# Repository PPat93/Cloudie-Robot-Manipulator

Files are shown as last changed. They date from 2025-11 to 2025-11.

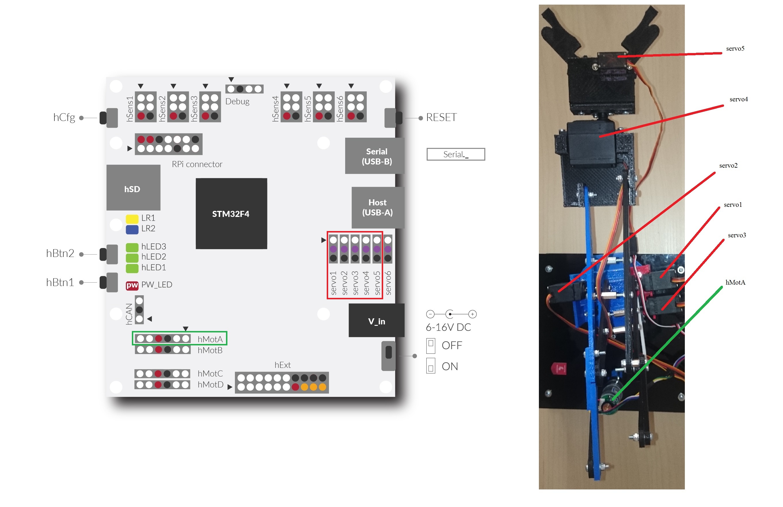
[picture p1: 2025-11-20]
electrical-wiring.jpg

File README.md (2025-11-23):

# Cloudie - 5-DOF Robotic Arm


## Overview
cloudie-duze png-1
Cloudie is a robot arm with five degrees of freedom that I created from scratch (with an overall construction inspiration from MeArm) during one of my university internships in 2016. 
Its closed-kinematic-chain architecture provides several advantages over open-chain designs - most notably higher load capacity and improved rigidity.

A key design choice was to place four of the six drives on the base, significantly reducing the mass of the moving arm. This leads to:
- higher positioning precision,
- lower inertia,
- reduced mechanical stress on the structure.

# What Cloudie Is Made Of?
Cloudie is built from a combination of 3D-printed components, servos, a DC motor with encoder, and a collection of miscellaneous parts. Its heart is the Husarion's Core2 board.

Precise List:
- 4 x TowerPro MG995 servos
- 1 TowerPro MG90S servo
- 1 DC motor with encoder
- 1 GT2 timing beltbearing
- 2 x 6000-2RS bearing
- Husarion CORE2
- 3D printed parts
- M3 screws, washers and nuts, servo screws
- several ASG BBs for the base 

## Components for printing
Below is a table with the parts that need to be printed in order to build the manipulator. Models, created in OpenSCAD format, can be found in the appropriate folder in the repository. 
mechnical-parts-list-and-numbers

# Pics











# Clips
## Separate movement:
[Separate movement](https://youtu.be/uYkaFl4qGg0)

## Rectlinear movement
[Rectlinear movement](https://youtu.be/c3nKy4OTICQ)

## Coordinates movement
[Coordinates movement](https://youtu.be/PuT0RdOZupA)

# Inversed kinematics calculations
The inverse kinematics of the manipulator was calculated manually based on the geometric relationships between its joints and connectors. These calculations allowed for the precise determination of the joint angles required to place the gripper in the desired position in space. I derived the equations based on the previously designed arm components and its complex structure. As a result, the manipulator can reach target points and follow predetermined trajectories.
The diagrams and calculations are presented below. Each diagram shows one cast of the manipulator (or part thereof).

## Calculations - Part I
part1-graphics

## Calculations - Part II 
part2-graphics

## Cleaned up calculations and results
final-cleaned-up-calcs

# Control and movement
I have created three ways to control Cloudie: separate, rectilinear, and coordinates movements. Each of them allows for a different type of motion, depending on needs. Originally, the manipulator control was designed to work via the Internet – through the HusarionCloud solution. Therefore, each original software folder contains both the code itself and a simple HTML page of the user interface used to operate the manipulator. 

## Separate movement 
The manipulator moves each drive individually - each joint separately. Works the same as in an excavator. One key = one joint.
joints-movement

## Rectlinear movement
The manipulator moves only in a straight line – along the imaginary X, Y and Z axes. One key = one axis.
rectlinear-movement-graph

## Coordinates movement  
The manipulator moves directly to predefined Cartesian coordinates. Its zero point (0,0,0) is located at the base of the manipulator - in the middle of the base bearing. The coordinates are entered up front and accepted with a single button press. 
coordinates-movement-graph

# Assembly
It’s highly recommended to assemble Cloudie from the base up to the gripper.
Starting elsewhere may cause difficulties when connecting the rotating base to the rest of the arm.
Most of the assembly process is straightforward - except for the gripper, which requires a bit more attention. The illustration below demonstrates the correct assembly method.




Once the gripper is installed, the remaining steps simply involve attaching each segment progressively from base to end-effector.

# Wiring
Thanks to the design of the CORE2 control board, all servos and motor are connected directly to the designated connectors. The connections are simple, as shown in the diagram below.
electrical-wiring

# Controller
The control board used in the manipulator's design is Husarion's Core2. It allows for the simultaneous connection of 5 servo mechanisms and 4 motors with the possibility of control via the Internet.


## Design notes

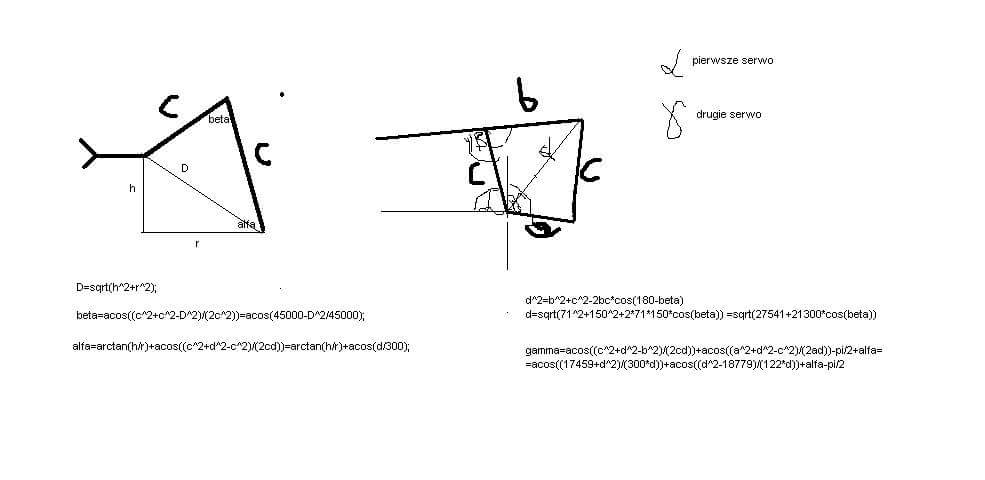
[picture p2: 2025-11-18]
orginal-kinematics-calcs/part1-original.jpg

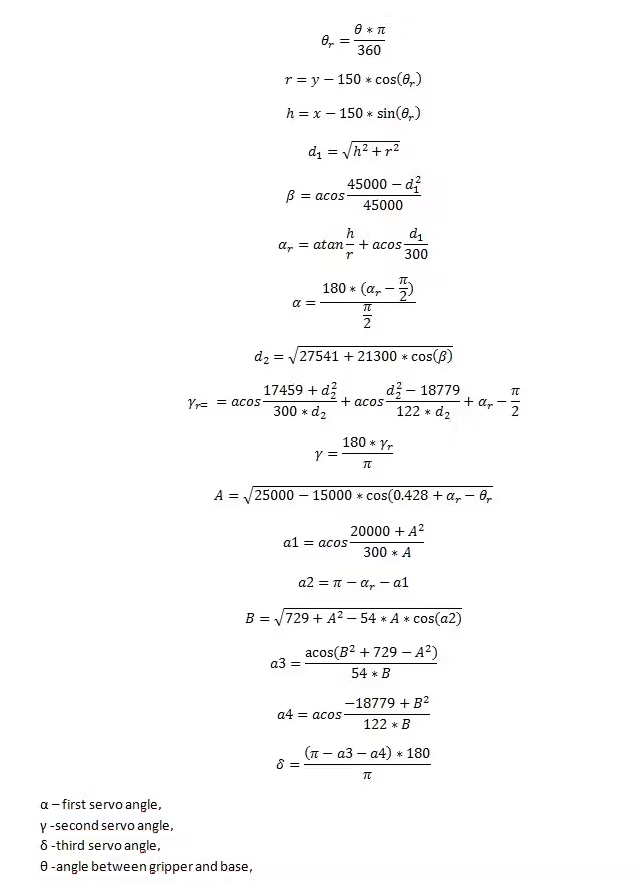
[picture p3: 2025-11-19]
revised-kinematics-calcs-and-graphics/final-cleaned-up-calcs.png

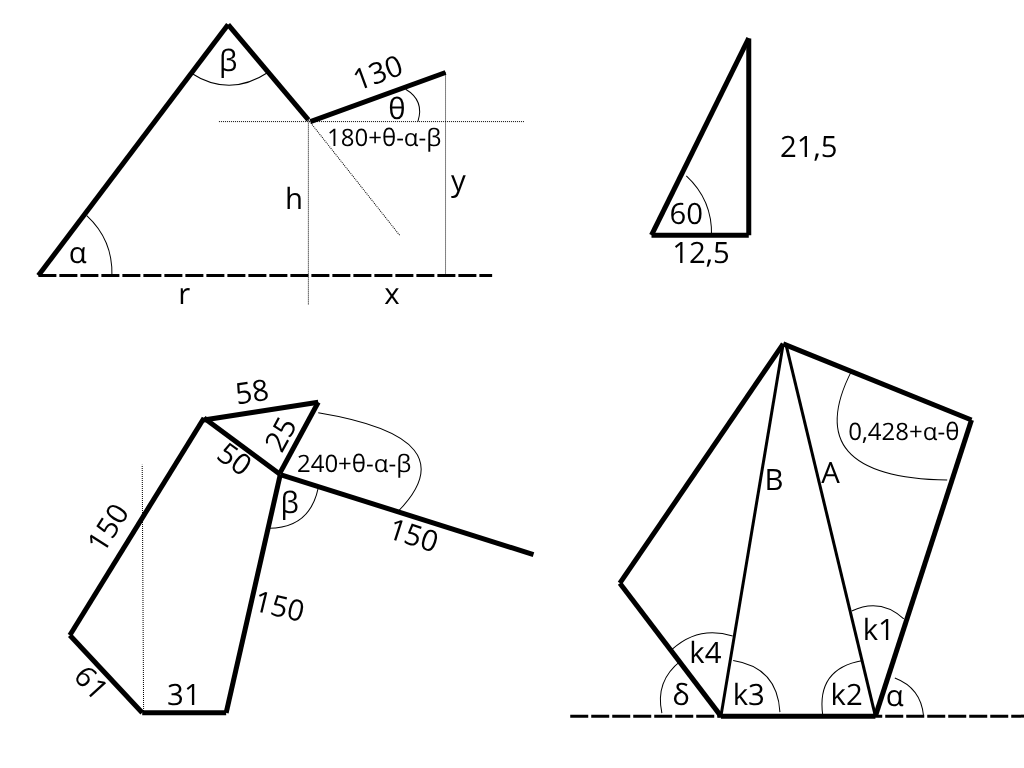
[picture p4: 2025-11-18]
revised-kinematics-calcs-and-graphics/part2-graphics.png

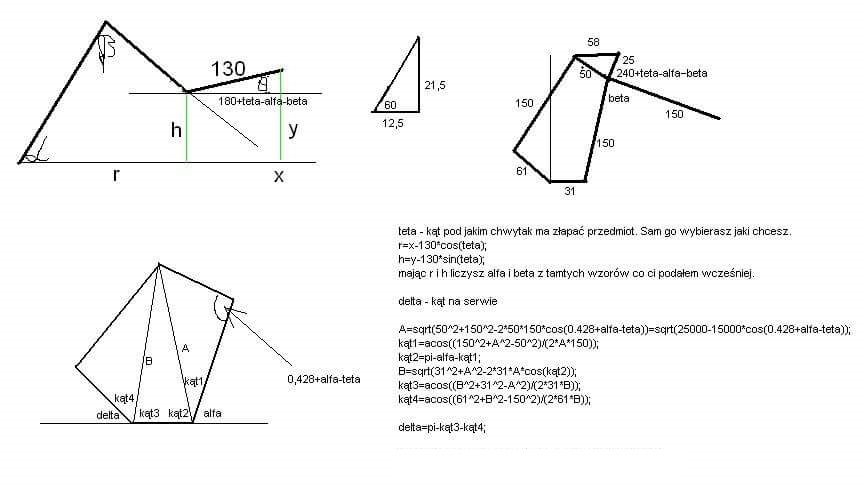
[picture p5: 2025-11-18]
orginal-kinematics-calcs/part2-original.jpg

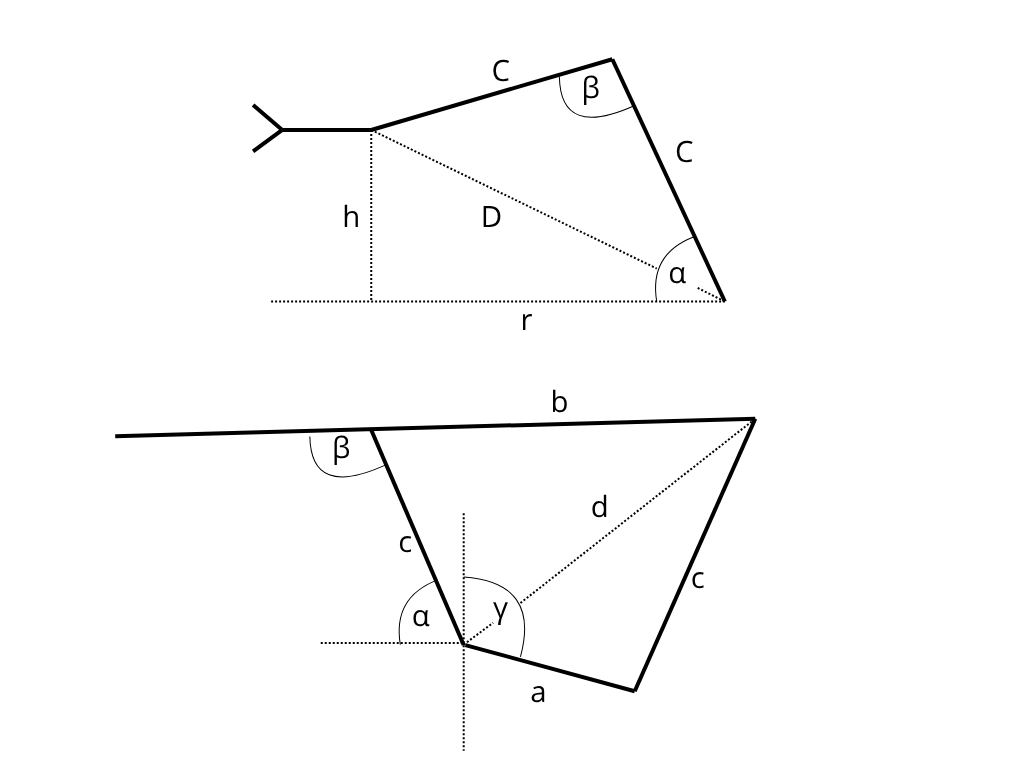
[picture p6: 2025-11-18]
revised-kinematics-calcs-and-graphics/part1-graphics.png

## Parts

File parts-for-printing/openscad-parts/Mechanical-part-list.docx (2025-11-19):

Mechanical part list:

No. | Part | Amount
1. | Down base | 1
2. | Right base bevel | 1
3. | Left base bevel | 1
4. | Longer servo horn gripper orientation | 2
5. | Center tilt | 1
6. | Main arm (servo) | 1
7. | Main arm (center) | 1
8. | Longer tilt | 3
9. | Gripper rotation base | 1
10. | Upper base | 1
11. | Moving base | 1
12. | Arm base | 1
13. | Long forearm | 1
14. | Short forearm | 1
15. | Four-bar linkage | 1
16. | Right servo bevel | 1
17. | Left servo bevel | 1
18. | Gripper frame 1 | 1
19. | Gripper frame 2 | 1
s20. | Manipulator gear | 1
21. | Motor gear | 1
22. | Manipulator shaft | 1
23. | Motor shaft | 1
24. | Motor gear ring | 1
25. | Manipulator gear ring | 1
26. | Manipulator ring bearing | 1
27. | Motor ring bearing | 1
28. | Gripper claw right | 1
29. | Gripper claw left | 1

Author: Piotr Paterek, Kraków 05-08.2016

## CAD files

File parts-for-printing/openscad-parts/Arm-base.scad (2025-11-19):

//Author: Piotr Paterek, Kraków 05-08.2016
$fn=50;
difference()
{
    difference()
    {
        difference()
    {
        difference()
    {
    difference()
    {
        cube([100,60,5], center=true);
        translate([-35,-20,-3])
        {
            cylinder(r=1.5,h=6);
        }
    }
        translate([-35,20,-3])
        {
            cylinder(r=1.5,h=6);
        }
    }
    translate([35,-20,-3])
        {
            cylinder(r=1.5,h=6);
        }
    }
    translate([35,20,-3])
        {
            cylinder(r=1.5,h=6);
        }
    }
    //screw hole
    translate([0,0,-5])
        {
            cylinder(r=3,h=10);
        }
}
difference()
{
    translate([-5,0,21.5])
    {
        cube([3,60,43], center=true);
    }
    translate([-5,15,38.25])
    {
        rotate(a=90, v=[0,1,0])
        {
        cylinder(r=1.5, h=3, center=true);
        }
    }
}
translate([0,-15,0])
{
    
rotate(a=90,v=[1,0,0])
{
    linear_extrude(height=5, convexity = 10){
    polygon(points=[[-5,15],[6,2],[-5,2]]);
    }
}
}
translate([0,20,0])
{
    
rotate(a=90,v=[1,0,0])
{
    linear_extrude(height=5, convexity = 10){
    polygon(points=[[-5,15],[6,2],[-5,2]]);
    }
}
}
translate([0,20,0])
{
    
rotate(a=90,v=[1,0,0])
{
    linear_extrude(height=5, convexity = 10){
    polygon(points=[[-5,15],[-20,2],[-5,2]]);
    }
}
}
translate([0,-15,0])
{
    
rotate(a=90,v=[1,0,0])
{
    linear_extrude(height=5, convexity = 10){
    polygon(points=[[-5,15],[-20,2],[-5,2]]);
    }
}
}

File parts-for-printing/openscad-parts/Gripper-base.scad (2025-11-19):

//Author: Piotr Paterek, Kraków 05-08.2016
$fn=20;
module base()
{
    cube([54,36,7], center=true);
    translate([0,15.5,11.5])
    {   
        cube([54,5,18.5], center=true);
    }
}
 
difference()
        {
    difference()
        {
        difference()
            {
                difference()
                    {
                    difference()
                        {
                        difference()
                            {
                            difference()
                            {
                                 base();
                                translate([0,15.5,11.5])
                                {
                                    rotate(a=90, v=[1,0,0])
                                    {
                                        cylinder(r=3.5, h=5, center=true);
                                    }
                                }
                            }
                             translate([9,15.5,11.5])
                                {
                                    rotate(a=90, v=[1,0,0])
                                    {
                                        cylinder(r=1, h=5, center=true);
                                    }
                                }
                            }
                        translate([9,15.5,11.5])
                            {
                                rotate(a=90, v=[1,0,0])
                                {
                                    cylinder(r=1, h=5, center=true);
                                }
                            }
                        
                    translate([-9,15.5,11.5])
                            {
                                rotate(a=90, v=[1,0,0])
                                {
                                    cylinder(r=1, h=5, center=true);
                                }
                            }
                        }
                translate([-19,15.5,8.5])
                    {
                        rotate(a=90, v=[1,0,0])
                        {
                            cylinder(r=1.6, h=5, center=true);
                        }
                    }
                }
        translate([19,15.5,8.5])
            {
                rotate(a=90, v=[1,0,0])
                {
                    cylinder(r=1.6, h=5, center=true);
                }
            }
        }
    translate([-12,-14,0])
            {
                
                    cylinder(r=1.7, h=7, center=true);
                
            }
        }
translate([12,-14,0])
        {
            
                cylinder(r=1.7, h=7, center=true);
            
        }
    }

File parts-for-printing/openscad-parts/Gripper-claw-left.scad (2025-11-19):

//Author: Piotr Paterek, Kraków 05-08.2016
$fn=40;
module claw()
{

    difference()
    {
        difference()
        {
            cylinder(r=15,h=5, center=true);
            cylinder(r=1.7,h=5, center=true);
        }
        
            for(i=[2.5:1:12.5])
            {
                rotate(a=i*270/11, v=[0,0,1])
                {
                    translate([15,0,0])
        {
                    
                        cylinder(r=2,h=5.2, center=true);
        }
                }
            }
    }
   


translate([31,0,0])
{
    cube([40,10,5], center=true);
}
translate([42,10,0])
{
    cube([40,10,5], center=true);
}
}


        difference()
        {
            claw();
            translate([42,48,0])
            {
                cylinder(r=37.5, h=6, center=true);
            }
        }
    

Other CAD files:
parts-for-printing/openscad-parts/Gripper-claw-right.scad
parts-for-printing/openscad-parts/Base down.scad
parts-for-printing/openscad-parts/Four-bar-linkage.scad
parts-for-printing/openscad-parts/Gripper-frame-2.scad
parts-for-printing/openscad-parts/Gripper-rotation-base.scad
parts-for-printing/openscad-parts/Left-base-bevel.scad
parts-for-printing/openscad-parts/Left-servo-bevel.scad
parts-for-printing/openscad-parts/Long-forearm.scad
parts-for-printing/openscad-parts/Longer-servo-horn-gripper-orientation.scad
parts-for-printing/openscad-parts/Longer-tilt.scad
parts-for-printing/openscad-parts/Main-arm-center.scad
parts-for-printing/openscad-parts/Main-arm-servo.scad
parts-for-printing/openscad-parts/Manipulator-gear-ring.scad
parts-for-printing/openscad-parts/Manipulator-gear.scad
parts-for-printing/openscad-parts/Manipulator-ring-bearing.scad
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

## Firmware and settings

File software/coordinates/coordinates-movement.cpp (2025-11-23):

//Author: Piotr Paterek, Krak�w 05-08.2016
//Coordinates Movement

#include "hFramework.h"
#include "hCloudClient.h"

float x;
float y;
float z;
float teta = 0;
float alfa = 0;
float beta;
float gamma1 = 0;
float delta = 0;
float tetar;
float kappa = 0;
float psi = -50;
float z1;
int i;
int mot1;


hPIDRegulator pidReg;

void debugConsole_task()
{
	char ch;

	platform.printf("Wpisz znak:\r\n");
	for (;;) {
		if (platform.read(&ch, 1) == 1) {
			platform.printf("echo: %c\r\n", ch);
		}
	}
}

void status_task()
{
	while (1) {
		platform.ui.label("lb_bat").setText("%2f V", sys.getSupplyVoltage());
		platform.ui.progressBar("pb_bat").setValue(sys.getSupplyVoltageMV() / 15); //supply voltage milivolts

		sys.delay(200);
	}
}
void cfgHandler()
{
	auto l1 = platform.ui.label("l1");
	auto l2 = platform.ui.label("l2");
	auto b = platform.ui.button("btn1");
	auto slider = platform.ui.input("slider1");
	auto input = platform.ui.input("text");
	platform.ui.loadHtml({Resource::WEBIDE, "/ui.html"});
//	platform.ui.video.enable();
}

void onValueChangeEvent(hId id, const char* data)   // text box handling
{
	LED1.toggle();
	//platform.ui.console("cl1").printf("qq ");
	if (id == "slider1") {
		int val = atoi(data);

//		platform.ui.console("cl1").printf("slider %s changed to %d \n", id.str(), val);
	} else if (id == "wspX") {
		x = atoi(data);
//		platform.ui.console("cl2").printf("na %s jest wspolrzedna x = %f \n", id.str(), x);
	} else if (id == "wspY") {
		y = atoi(data);
//		platform.ui.console("cl2").printf("na %s jest wspolrzedna y = %f \n", id.str(), y);
	} else if (id == "wspZ") {
		z = atoi(data);
//		platform.ui.console("cl2").printf("na %s jest wspolrzedna z = %f \n", id.str(), z);
	} else if (id == "katTeta") {
		teta = atoi(data);
//		platform.ui.console("cl2").printf("na %s jest wspolrzedna z = %f \n", id.str(), teta);

	}


}

void onKeyEvent(KeyEventType type, KeyCode code)            //keys handling
{

	switch (code) {
	case KeyCode::Key_A:
		if (type == KeyEventType::Pressed) {
			i = 5;
		}
		if (type == KeyEventType::Released) {
			i = 0;
		}
		break;
	case KeyCode::Key_D:
		if (type == KeyEventType::Pressed) {
			i = 6;
		}
		if (type == KeyEventType::Released) {
			i = 0;
		}
		break;
	case KeyCode::Key_W:
		if (type == KeyEventType::Pressed) {
			i = 7;
		}
		if (type == KeyEventType::Released) {
			i = 0;
		}
		break;
	case KeyCode::Key_S:
		if (type == KeyEventType::Pressed) {
			i = 8;
		}
		if (type == KeyEventType::Released) {
			i = 0;
		}
		break;
	case KeyCode::Key_Z:
		if (type == KeyEventType::Pressed) {
			i = 9;
		}
		break;
	case KeyCode::Key_X:
		if (type == KeyEventType::Pressed) {
			i = 0;
		}

		break;

	}
}



void servoMotionXYZ()
{
	hServoModule.s1.calibrate(-90, 2400, 90, 800); //servo calibrations
	hServoModule.s2.calibrate(-90, 2400, 90, 800);
	hServoModule.s3.calibrate(-90, 800, 90, 2400);
	hServoModule.s4.calibrate(-90, 800, 90, 2400);
	hServoModule.s5.calibrate(-90, 800, 90, 2400);

	while (1) {                     //inversed kinematics calculations
		sys.delay(10);

		tetar = teta * M_PI / 180;
		float r = y - 150.0 * cosf(tetar);
		float h = x - 150.0 * sinf(tetar);

		float d1 = sqrt(pow(h, 2) + pow(r, 2));
		float betar = acosf((45000.0 - pow(d1, 2)) / (45000.0));
		beta = betar;

		float alfar = atanf(h / r) + acosf(d1 / 300.0);
		alfa = (180 * (alfar - (M_PI / 2))) / M_PI; //first servo angles

		float d2 = sqrt(27541.0 + 21300.0 * cosf(betar));

		float gammar = acosf((17459.0 + pow(d2, 2)) / (300.0 * d2)) + acosf((pow(d2, 2) - 18779) / (122 * d2)) + alfar - (M_PI / 2);
		gamma1 = (180.0 * (gammar)) / M_PI;  // second servo angles

		float A = sqrt(25000.0 - 15000.0 * cosf(0.428 + alfar - tetar));
		float  kat1 = acosf((20000.0 + pow(A, 2)) / (300.0 * A));
		float kat2 = M_PI - alfar - kat1;
		float B = sqrt(pow(27, 2) + pow(A, 2) - 2 * 27 * A * cosf(kat2));
		float kat3 = acosf((pow(B, 2) + pow(27, 2) - pow(A, 2)) / (54 * B));
		float kat4 = acosf((-18779.0 + pow(B, 2)) / (122.0 * B));

		delta = (M_PI - kat3 - kat4) * 180.0 / M_PI; // third servo angles
            z1 = 8300*z/360;                                                  

		if (i == 5) {                                   //servo angles with limits
			if (kappa > 90) {
				kappa = 90;
			}
			kappa += 2;
			hServoModule.s4.rotAbs(kappa);

			platform.ui.console("cl1").printf("Psi =  %f \n", psi);
			platform.ui.console("cl1").printf("Kappa =  %f \n", kappa);
			platform.ui.console("cl1").printf("--------------------------\n");

		} else if (i == 6) {
			if (kappa < -90) {
				kappa = -90;
			}
			kappa -= 2;
			hServoModule.s4.rotAbs(kappa);

			platform.ui.console("cl1").printf("Psi =  %f \n", psi);
			platform.ui.console("cl1").printf("Kappa =  %f \n", kappa);
			platform.ui.console("cl1").printf("--------------------------\n");

		} else if (i == 7) {
			if (psi > -40) {
				psi = -40;
			}
			psi += 2;
			hServoModule.s5.rotAbs(psi);

			platform.ui.console("cl1").printf("Psi =  %f \n", psi);
			platform.ui.console("cl1").printf("Kappa =  %f \n", kappa);
			platform.ui.console("cl1").printf("--------------------------\n");

		} else if (i == 8) {
			if (psi < -110) {
				psi = -110;
			}
			psi -= 2;
			hServoModule.s5.rotAbs(psi);

			platform.ui.console("cl1").printf("Psi =  %f \n", psi);
			platform.ui.console("cl1").printf("Kappa =  %f \n", kappa);
			platform.ui.console("cl1").printf("--------------------------\n");

		} else if (i == 9) {                        // motor handling
			if (hMot1.getEncoderCnt() +5 < z1) {
				if (1) {
					sys.delay(10);
					hMot1.rotAbs(hMot1.getEncoderCnt() + 5);
				}

				platform.ui.console("cl1").printf("Encoder ticks =  %d \n", hMot1.getEncoderCnt());



			} else if (hMot1.getEncoderCnt() - 5 > z1) {
				if (1) {
					sys.delay(10);
					hMot1.rotAbs(hMot1.getEncoderCnt() - 5);
				}
				platform.ui.console("cl1").printf("Encoder ticks =  %d \n", hMot1.getEncoderCnt());




			} else if (hMot1.getEncoderCnt() == z1) {

				hMot1.setPower(0);

			} else {

			}
		}
	}
}




void motor()                        //pid regulator for motor
{
	// hPID
	pidReg.setScale(1);
	pidReg.setKP(39.0);
	pidReg.setKI(0.05);
	pidReg.setKD(1000);
// hRegulator
	pidReg.dtMs = 5;
	pidReg.stableRange = 10;
	pidReg.stableTimes = 3;

	hMot1.attachPositionRegulator(pidReg);

}


void onButtonEvent(hId id, ButtonEventType type)                //button handling
{


	UiButton b = platform.ui.button("btn1");
	if (id == "btn1") {
		if (type == ButtonEventType::Pressed) {

			platform.ui.console("cl2").printf("Alfa =  %f \n", alfa);
			platform.ui.console("cl2").printf("Gamma =  %f \n", beta);
			platform.ui.console("cl2").printf("Delta =  %f \n", gamma1);
			platform.ui.console("cl2").printf("-------------------------\n");

			hServoModule.s1.rotAbs(alfa);
			hServoModule.s2.rotAbs(gamma1);
			hServoModule.s3.rotAbs(delta);



		}
	}
}
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

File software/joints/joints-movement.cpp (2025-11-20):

//Author: Piotr Paterek, Krak�w 05-08.2016
//Joints movement

#include "hFramework.h"
#include "hCloudClient.h"

bool keyW = false;
bool keyS = false;
bool keyA = false;
bool keyD = false;


hPIDRegulator pidReg;



int i = 0;
int m = 0;
int n = 0;
float s;
int mot1 = 0;
int mot2 = 0;


float angle1 = -5;
float angle2 = 10;
float angle3 = 13;
float angle4 = -5;
float angle5 = -11;


hGPIO& lightLeft = hSens1.pin1;
hGPIO& lightRight = hSens2.pin1;

void debugConsole_task()
{
	char ch;

	platform.printf("Wpisz znak:\r\n");
	for (;;) {
		if (platform.read(&ch, 1) == 1) {
			platform.printf("echo: %c\r\n", ch);
		}
	}
}

void status_task()
{
	while (1) {
		platform.ui.label("lb_bat").setText("%2f V", sys.getSupplyVoltage());
		platform.ui.progressBar("pb_bat").setValue(sys.getSupplyVoltageMV() / 15); //supply voltage milivolts

		sys.delay(200);
	}
}

void motorMotion()//pid regulator for the motor
{
	// hPID
	pidReg.setScale(1);
	pidReg.setKP(39.0);
	pidReg.setKI(0.05);
	pidReg.setKD(1000);
// hRegulator
	pidReg.dtMs = 5;
	pidReg.stableRange = 10;
	pidReg.stableTimes = 3;

	hMot1.attachPositionRegulator(pidReg);

}

void cfgHandler()
{
	auto l1 = platform.ui.label("l1");
	auto l2 = platform.ui.label("l2");
	auto b = platform.ui.button("btn1");
	auto slider = platform.ui.input("slider1");
	auto input = platform.ui.input("text");
	platform.ui.loadHtml({Resource::WEBIDE, "/ui.html"});
//	platform.ui.video.enable();
}

void servoMotionSeparately()
{

	hServoModule.s1.calibrate(-90, 2400, 90, 800);  // servos calibration
	hServoModule.s2.calibrate(-90, 2400, 90, 800);
	hServoModule.s3.calibrate(-90, 800, 90, 2400);
	hServoModule.s4.calibrate(-90, 800, 90, 2400);
	hServoModule.s5.calibrate(-90, 800, 90, 2400);

	while (1) {

		sys.delay(10);
		if (i == 1) {                   //following angles on servos with limits

			angle1 += 2;
			if (angle1 > -5) {
				angle1 = -5;
			}
			sys.delay(30);
			platform.ui.console("cl1").printf("Angle3  =  %f \n", angle3);
			platform.ui.console("cl1").printf("Angle2  =  %f \n", angle2);
			platform.ui.console("cl1").printf("Angle1 = %f \n", angle1);
			platform.ui.console("cl1").printf("--------------------------\n");
			hServoModule.s1.rotAbs(angle1);
		} else if (i == 2) {
			angle1 -= 2;

			if (angle1 < -90) {
				angle1 = -90;
			}
			sys.delay(30);
			platform.ui.console("cl1").printf("Angle3  =  %f \n", angle3);
			platform.ui.console("cl1").printf("Angle2  =  %f \n", angle2);
			platform.ui.console("cl1").printf("Angle1 = %f \n", angle1);
			platform.ui.console("cl1").printf("--------------------------\n");
			hServoModule.s1.rotAbs(angle1);

		} else if (i == 3) {
			angle2 += 2;

			if (angle2 > 83) {
				angle2 = 83;
			}
			sys.delay(30);
			platform.ui.console("cl1").printf("Angle3  =  %f \n", angle3);
			platform.ui.console("cl1").printf("Angle2  =  %f \n", angle2);
			platform.ui.console("cl1").printf("Angle1 = %f \n", angle1);
			platform.ui.console("cl1").printf("--------------------------\n");
			hServoModule.s2.rotAbs(angle2);
		} else if (i == 4) {
			angle2 -= 2;

			if (angle2 < -10) {
				angle2 = -10;
			}
			sys.delay(30);
			platform.ui.console("cl1").printf("Angle3  =  %f \n", angle3);
			platform.ui.console("cl1").printf("Angle2  =  %f \n", angle2);
			platform.ui.console("cl1").printf("Angle1 = %f \n", angle1);
			platform.ui.console("cl1").printf("--------------------------\n");
			hServoModule.s2.rotAbs(angle2);
		} else if (i == 5) {
			angle3 -= 2;
			if (angle3 < -35) {
				angle3 = -35;
			}
			sys.delay(30);
			platform.ui.console("cl1").printf("Angle3  =  %f \n", angle3);
			platform.ui.console("cl1").printf("Angle2  =  %f \n", angle2);
			platform.ui.console("cl1").printf("Angle1 = %f \n", angle1);
			platform.ui.console("cl1").printf("--------------------------\n");
			hServoModule.s3.rotAbs(angle3);

		} else if (i == 6) {
			angle3 += 2;
			if (angle3 > 82.5) {
				angle3 = 82.5;
			}
			sys.delay(30);
			platform.ui.console("cl1").printf("Angle3  =  %f \n", angle3);
			platform.ui.console("cl1").printf("Angle2  =  %f \n", angle2);
			platform.ui.console("cl1").printf("Angle1 = %f \n", angle1);
			platform.ui.console("cl1").printf("--------------------------\n");
			hServoModule.s3.rotAbs(angle3);


		} else if (i == 7) {
			angle4 -= 5;
			if (angle4 < -90) {
				angle4 = -90;
			}
			sys.delay(30);
			platform.ui.console("cl2").printf("Angle4  =  %f \n", angle4);
			platform.ui.console("cl2").printf("Angle5  =  %f \n", angle5);
			platform.ui.console("cl2").printf("--------------------------\n");
			hServoModule.s4.rotAbs(angle4);


		} else if (i == 8) {
			angle4 += 5;
			if (angle4 > 90) {
				angle4 = 90;
			}
			sys.delay(30);
			platform.ui.console("cl2").printf("Angle4  =  %f \n", angle4);
			platform.ui.console("cl2").printf("Angle5  =  %f \n", angle5);
			platform.ui.console("cl2").printf("--------------------------\n");
			hServoModule.s4.rotAbs(angle4);

		} else if (i == 9) {
			angle5 -= 5;
			if (angle5  < -120) {
				angle5  = -120;
			}
			sys.delay(30);
			platform.ui.console("cl2").printf("Angle4  =  %f \n", angle4);
			platform.ui.console("cl2").printf("Angle5  =  %f \n", angle5);
			platform.ui.console("cl2").printf("--------------------------\n");
			hServoModule.s5.rotAbs(angle5);

		} else if (i == 10) {
			angle5  += 5;
			if (angle5  > -11) {
				angle5  = -11;
			}
			sys.delay(30);
			platform.ui.console("cl2").printf("Angle4  =  %f \n", angle4);
			platform.ui.console("cl2").printf("Angle5  =  %f \n", angle5);
			platform.ui.console("cl2").printf("--------------------------\n");
			hServoModule.s5.rotAbs(angle5);

		} else if (i == 11) {

			mot1 = 10;
			hMot1.rotRel(mot1);
			sys.delay(30);


		} else if (i == 12) {

			mot1 = -10;
			hMot1.rotRel(mot1);

			sys.delay(30);
		} else {
			i = 0;
			mot1 = 0;

		}
	}
}
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

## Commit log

2025-11-19 v0.03 - add revised, cleaned up calculations in a form of image, add image of the electrical wiring, uniy naming across repo
2025-11-19 v0.04 - added compressed parts for 3d pritning and removed no longer necessary kinematics file
2025-11-19 v0.04 - add unpacked parts
    [Arm-base.scad, Base down.scad, Four-bar-linkage.scad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]
2025-11-20 v0.05 - update electrical wiring with colors
2025-11-20 v0.05 - add separate joints movement
2025-11-23 v0.06 - add list of mechanical parts for printing and their required number
2025-11-23 v1.0 - remove duplicated original kinematics folder, some misspronounciation and start working on Readme
2025-11-23 v1.0 - delete duplicated revised kinematics folder
2025-11-23 Complete Readme
    Added images and sections for movement control and wiring.
